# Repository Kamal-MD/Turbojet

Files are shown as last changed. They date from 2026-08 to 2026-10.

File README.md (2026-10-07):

Project description: homemade turbojet made from a salvaged turbocharger, propane fueled, ground test only\
Current Status: Found Turbocharger, broken compressor seal ring but in good condition\
Current Reference: HX35 Turbo\
Key points:
+ Fuel: Propane
+ Compression Ratio: 2.4
+ Air mass flow: 0.212 kg/s
+ Compressor Exit Temp/Combustor Inlet T2: 400K ~ 127C
+ Turbine Inlet Target, T4: 880K ~ 606.7C
+ FAR_stoichiometric: 0.0642
+ φ_overall: 0.19

Note: Not for flight

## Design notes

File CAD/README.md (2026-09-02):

All CAD modeling is done using Autodesk Fusion

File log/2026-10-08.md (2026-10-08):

**What I did:** Determined the φ in each zone, as well as the operating temp of each zone\
**Details:**
+ For the primary zone, we use φ = 1 since that is when the temperature, and therefore the combustion rate is highest. This means it can keep up with the fast flowing air without being extinguished
+ For secondary zone, we use φ = 0.6 (tentative), because it is what is used in most turbojet designs, and because its operating temperature is cool enough for CO2 to remain CO2 without dissociation but hot enough that CO burns into CO2
+ The rest of air goes to dilution, such that the overall  φ = 0.19
+ The operating temps and air splits in each zone are in the table below, which was generated by Claude, and Claude also aided in the calculations:

## Combustor zone design

**φ_overall = 0.189 (calculated), rounded to 0.19 for design.**

| Zone | φ (cumulative) | f | Cumulative air | Air added in zone | T (formula) | Expected real T | Purpose |
|---|---|---|---|---|---|---|---|
| Primary | 1.0 | 0.0642 | 19.0% | 19.0% | ~2551 K | ~2350 K (Cantera to confirm) | Stable flame in recirculation bubble |
| Secondary | 0.6 (provisional) | 0.0385 | 31.7% | 12.7% | ~1775 K | Somewhat lower (Cantera to confirm) | Burn out CO left by primary zone |
| Dilution | 0.19 | 0.0122 | 100% | 68.3% | ~882 K (609 °C) | ~882 K | Cool to T4 target, even out profile |

**Design fuel flow:** 0.0122 × 0.212 kg/s ≈ 2.6 g/s propane

**Formulas:**
- f_zone = φ_zone × FAR_st
- T_zone = T3 + (f · LHV · η_b) / ((1 + f) · c_p)
- X_zone = φ_overall / φ_zone

**Assumptions:** propane, FAR_st = 0.0642, LHV = 46,350 kJ/kg, T3 = 400 K, ṁ_air = 0.212 kg/s, all fuel injected at the flange. c_p = 1.3 / 1.25 / 1.1 kJ/kg·K (primary / secondary / dilution). η_b = 1.0 for hot zones (ideal, comparable to Cantera), 0.95 at exit.

**Notes:**
- Rounding φ_overall up from 0.189 to 0.19 raises T4 from 879.9 K to ~882.4 K (+2.5 K), well inside the 25% margin to the 900 °C turbine limit.
- Primary and secondary temperatures depend only on each zone's own φ, so they're unaffected by the rounding.
- Formula temperatures ignore dissociation, so the hot zones are overestimated.
- Wall-cooling air is not yet allocated; scheduled for Oct 10. It will come out of the 68.3% dilution share.

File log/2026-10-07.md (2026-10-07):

**What I did:** Calculated the stoichiometric Fuel-to-Air ratio for propane (FAR = 0.0642) and the overall equivalence ratio (0.19) that the combustion chamber should run on\
**Details:** To determine the amount of fuel and air to inject, as well as the percentage of air in the chamber zones (in the future), we need the stoich. FAR and overall equivalence ratio:
+ C₃H₈ + 5 (O₂ + 3.76 N₂) → 3 CO₂ + 4 H₂O + 18.8 N₂ (O2 is about 21 percent of air, meaning nitrogen gas is about 79 percent; therefore, there is about 3.76 N2 for 1 O2 (in mols))
+ Using the respective molar masses of the reactants, we see that m(C₃H₈) = 44.1g while m(air)= 686.5g. So stoichiometric FAR = 0.0642
+ This means that 1 kg of air burns around 64 grams of propane
+ The equivalence ratio φ is actual FAR/stoichiometric FAR (where if φ=1 combustion is stoichiometric, if φ<1 it is lean or has leftover O2, if φ>1 it has unburned leftover fuel)

Thus, we have to get FAR_actual:
+ FAR · LHV · η_b = (1 + FAR) · c_p · (T_out − T_in)  (where we have T_in = T2 = 400K or 126Celcius, and T_out = T4 = 880K or 606.7C)
+ LHV = Propane's Lower Heating Value = 46.35 (MJ/Kg); LHV is the amount of heat released when a fuel is completely burned
+ η_b(combustion efficiency) = 0.95 (This is an assumption, since we can know when we run experiments)
+ c_p (average specific heat of the hot gas): ~1.1 kJ/kg·K over this range
+ So, FAR_actual (overall) is around 0.012
+ φ_overall = FAR_actual(overall)/FAR_stoichiometric = 0.012/0.0642 ~ 0.19
  
**Problem:**
+ Propane's lean flammability limit (you could think of it as the equivalence ratio, or percentage of stoichiometric fuel needed to sustain combustion) is φ=0.5, or around 32 grams of propane
+ So we must do 2 contradictory things: Operate chamber at a φ that sustains propane's combustion and have it reach the turbine at φ_overall = 0.19 to avoid damaging it
+ Common practice in dealing with this (as is seen in commercial turbojets) is using zones to admit the air in stages, where the majority of combustion happens in the primary stage and the rest of the stages are used to finish combustion and cool it down

**What to do next:**
+ Figure out the operating temperature for each air zone such that the air reaches the turbine at around 606 Celcius (I don't mind being a little higher than that, but being below means we are losing out on energy. I will explain why in the next log)
+ From the operating temperature, determine the percentage of air that should pass through each zone to maximize efficiency (while remaining safe of course)
+ Granted, I might work on part of this today since I still have some time, but I will log any progress towards this for tomorrow (Oct 8)

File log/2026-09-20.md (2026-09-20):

**What I did:** I Bought a turbocharger and started cleaning it\
**Details:**
+ Went to a junkyard and bought a turbocharger for 30 usd
+ Took it home and started cutting off the exhaust manifold
+ Ran into a material drawback; I didn't have a wheel (for my circular electric saw) that was big enough to cut all the way through the exhaust manifold\
  
**Note:** Post pictures showing you cutting the manifold\
**What to do next:**
+ Since I can't get the wheel for a while, I'll clean the turbo, disassemble it, clean it from the inside
+ After that, I will look up the model and take measurement of the intake and outlet for both the turbine and compressor and measure turbine housing thickness to determine temp ceiling
+ Finally, I will check the model in hopes of finding a compressor map for the turbo

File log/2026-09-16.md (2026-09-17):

**What I did:** Determined Turbine inlet temp ceiling\
**Details:**
+ From the following source (https://www.mambatek.com/en/products/mamba-d5-turbo-turbine-wheel-for-holset-hx35hx40-dodge-cummins-647655), material of HX35 is 713C Inconel
+ 713C Inconel has a  continuous-duty max operating temperature of around 980C, which I will be decreasing to 900C for safety reasons

**What to do next:**
  + Determine the turbine inlet temp (T3) that we want to operate at, account for safety margin
  + After determining T3, we will use it to determine fuel to air ratio
  + Check if the power generated is greater than compressor power demand, so that the engine self sustains and produces thrust

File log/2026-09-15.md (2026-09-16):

**What I did:** Short Session, I just set the goals and limitations to consider when building the combustion chamber\
**Details:**\
I set the following to take work on:\
**P1**
+ **Turbine inlet temperature ceiling** to make sure the turbine and turbine housing can handle the temperature of the air coming from the combustion chamber
+ **Chamber Liner tolerances and survival** which entail making sure that the chamber housing can tolerate peak temperatures without warping or burning through
+  **Accounting and minimizing for loss of pressure in chamber**

**P2**
+ **Combustion efficiency** (Helps minimize soot buildup among other things)
+ **Flame stability across operating range** to make sure that the engine can run during all stages (startup, throttle changes, etc.) and not just on one design point (which is the goal 28 lb/min (0.2117 kg/s)
+ **Make sure that temperature is uniform at the exit** (without hot streaks, since those will be the actual temp ceiling, not the average temp)

**P3**
+ **Ignition/startup reliability** (Can I source an igniter that can light it during startup?)
+ **Material sourcing feasibility**

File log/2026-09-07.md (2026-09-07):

**What I did:** Determined what the chamber inlet diameter should be\
**Details:**
+ Determined air density at compressor discharged since mass flow alone doesn't tell you velocity through a duct, you need density too. Used the ideal gas law: ρ = P / (R × T)  
Where:\
P = compressor discharge pressure = PR × P1 = 2.4 × 101,325 Pa ≈ 243,180 Pa\
R = specific gas constant for air = 287 J/(kg·K)\
T = compressor discharge temp = 400K (calculated in the Sept 1 session)\
And thus we got: ρ2 = 243,180 / (287 × 400) ≈ 2.12 kg/m³
+ Unlike the chamber inlet (a free design choice), the compressor's own outlet diameter is fixed hardware — 52mm ID, per the HX35 V-band spec. So velocity here isn't chosen, it falls straight out of known geometry via continuity:\
ṁ = ρ × A × V  →  V = ṁ / (ρ × A)\
Where:\
m = 0.2117 kg/s\
A (52 mm compressor outlet inner diameter) = π × (0.026)² ≈ 0.002124 m²\
Which gives us: V2 = 0.2117 / (2.12 × 0.002124) ≈ 47 m/s
+ Then to determine velocity across the connector's changning diameter I used:\
ṁ = ρA₁V₁ = ρA₂V₂\
Density is approx. constant over this short, low-Mach run, so it cancels:\
A₁V₁ = A₂V₂  →  V₂ = V₁ × (A₁/A₂)\
Since A = π(d/2)², the π/4 factor is on both sides and cancels too — area ratio becomes a diameter-squared ratio:\
A₁/A₂ = (d₁/d₂)²  →  V₂ = V₁ × (d₁/d₂)²\
+ First I applied this math along the compressor outlet, which starts at V1=47m/s and 52mm diameter as d1 (directly at the compressor outlet with the 52mm inner diameter)
and then 75.5 mm as d2, which is the diameter of the silicone hose at the compressor end. Thus, we get the air velocity at the compressor end of the hose to be ~22.3m/s
+ Then to determine the velocity at the chamber inlet, we use V1 = 22.3m/s, d1 = 75.5 mm (which is the hose inner diameter on the compressor end), and d2 =50 mm, which is the inner diameter placeholder we put in September 1's session.\
As such we get the chamber inlet velocity at ~51 m/s
+ Since the the inlet velocity of 51m/s agrees with most DIY turbojet literature (I don't have exact sources for radially arranged turbocharger turbojets, only for axially arranged turbojets), we are keeping the chamber inlet diameter as 50 mm and will widen the silicone hose to 50.5mm inner diameter to fit over it

**What to do next:**
+ Determine combustion chamber geometry
+ Will likely design the inlet stub as part of it, but this might change
+ Thoroughly plan how to design the combustion chamber

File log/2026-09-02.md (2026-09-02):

**What I did:** Changed compressor to chamber connector material from Aluminum to Silicone hose and modeled the silicone hose with a placeholder value\
**Details:**
+ Created a model for the HX35 compressor outlet in CAD for future reference: HX35 comp ref
+ Due to sourcing difficulties in Lebanon and the technical difficulty of making an Aluminum connector tube with a V-band flange, I decided to switch to using a silicone hose as a connector
+ This decision is due to the fact that silicone hoses can resist extreme temperatures of up to 250 degrees Celsius, which is a great margin over our projected compressor discharge temp of around 127 degrees (150 degrees in extreme cases and random spikes of temp)
+ The logic behind it is that I will buy a hose with an inner diameter slightly greater than that of the compressor outlet's V-band lip (74mm OD) and use a hose clamp behind the lip to create an airtight seal
+ Ideally, I would buy a hose of an inner diameter at the compressor end that differs from the diameter on the chamber end (Note: the hoses diameter at the compressor end is fixed at 75.5 mm, while the decision of having a smaller diameter at the chamber end can be subject to future change) 
+ This is the CAD file of the current version I made today:
placeholder comp to chamber connection

Dimensions:
+ **Hose compressor end inner diameter:** 75.5 mm
+ **Hose chamber end inner diameter:** 50 mm
+ **Hose wall thickness:** 4.5 mm
+ **Hose length:** 200 mm

**What to do next:**
+ Calculate the chamber inlet diameter
+ Model chamber inlet in CAD

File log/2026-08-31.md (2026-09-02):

**What was done:** Learned how to use CAD and settled on HX35 specs to use for reference\

**Details:**
+ Finished Days 1 to 9 in Product Design Online's 30 day Autodesk Fusion Course
+ Holset's official Service Repair Manual and Service Data Sheet don't publish flange bore/OD dimensions, so I used an HX35 listing (https://www.turbozentrum.de/Holset-HX35-Turbo-12cm_1) as reference
+ Did not do much Turbojet related CAD modeling today, but resolved whether the mounting type was V-band or bolted and on which side. 
+ Locked in [reference specs](/References/HX-35_Turbo.md), which will set up for Sept 1 and 2's session
  
**What to do Next:**
+ Model Compressor Outlet to Combustion Inlet connection
+ Specify Compression Ratio and Air conditions in the Combustion Inlet here on Github

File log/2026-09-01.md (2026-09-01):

**What was done:** Calculated Compressor Outlet Temperature, Material to use for Compressor to Chamber connection, Determined Compression Ratio and Energy the compressor requires\
**Details:**
+ The material to use for the compressor outlet to chamber inlet connection will be Aluminum, as its melting point is 660 degrees Celsius and the compressor discharge temperature is well below that (unlikely to exceed 150 degrees) Note: This decision can be subject to future change
+ To determine what material to use for the compressor outlet to chamber inlet connection, I had to determine Compressor Outlet Temperature. This was achieved by using the following equation:

  $$
  T_2 = T_1 \left[ 1 + \frac{PR^{\frac{\gamma - 1}{\gamma}} - 1}{\eta_c} \right]
  $$

  Where:\
  T1 = inlet air temperature (in Kelvin(K), ~ 288K on a normal day)\
  T2 = compressor discharge temp (in Kelvin)\
  PR = Pressure Ratio (or Compression Ratio)\
  gamma (y) = specific heat ratio for air (approximately 1.4)\
  n_c = compressor isentropic efficiency (meaning how efficient it is and how much goes towards internal losses such as turbulence and friction), typically around 0.65 - 0.75 for a turbocharger like this

  But keep in mind that the compression ratio (PR) has not been decided at this point (we need to determine a ratio where this specific turbo can run efficiently)
  
+ So, I found a compressor map for HX35 (which was unofficial but detailed) in the following link: (https://www.dsmtuners.com/threads/how-to-read-the-hx35-hx40-compressor-map-s.362599/)\
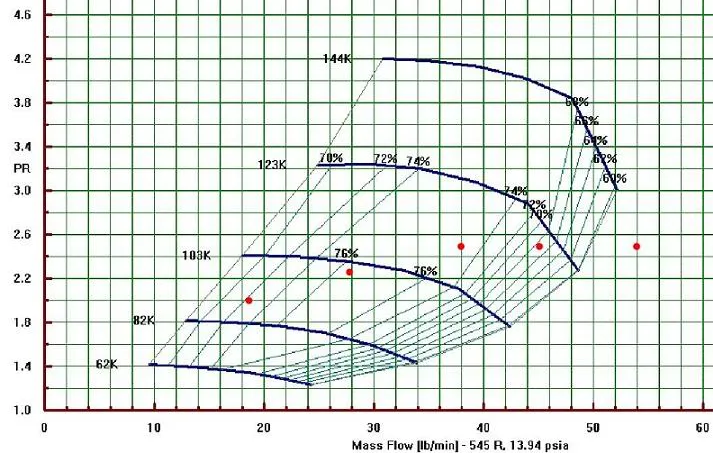
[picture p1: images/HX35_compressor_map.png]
HX35 Compressor Map
  This is it:
+ In reference to the map, we can see that an optimal efficiency of 76% is achieved at between a PR of 2.2 and 2.4. We will pick PR of 2.4
+ We are using n_c = 0.75 which is inferred off the map, since PR of 2.4 sits between 74% and 76.5% efficiency (so we will use 75% or 0.75 as a place in between)
  By inputting PR = 2.4 into the above equation, we get T2 ~ 400 Kelvin (specifically is 397K) which is around 127 degrees Celsius
+ Finally, we determined the work the compressor requires through the following equation:

$$
W_{\text{compressor}} = \dot{m}_{\text{air}} \cdot c_p \cdot (T_2 - T_1)
$$

Where: 

m(air) = mass flow rate of air (which I picked to be 28 lb/min or 0.2117 kg/s by looking at the map intersection of PR=2.4 at ~76% efficiency)\
c_p = specific heat for air ( around 1005 J/Kg*K)

And thus we get Wcompressor = 0.2117 kg/s * 1005 J/Kg*K * 112 K = 23.8 KW (KiloWatts)

**What to do next:**\
Tomorrow  on Sept 2:
+ I will design the compressor to chamber connection in CAD using Autodesk Fusion
+ If I have time, I will see how to figure out the power the turbine consumes and if the engine can self sustain (as I can't find a turbine map for HX35 turbo)

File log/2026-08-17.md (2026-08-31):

**What I did**: Decided on welding, materials for combustion chamber, and position of propane inlet\
**Decisions**:
+ I will weld the flanges onto the combustion chamber. First, I will weld the inner liner to the inside to the flange and the flange to the combustion chamber. Additionally, I will weld a flange onto the end of the chamber to fashion a flange joint on the turbine intake
+ The type of welding will be stick welding since I have a 50$ stick welding machine that fits within my budget
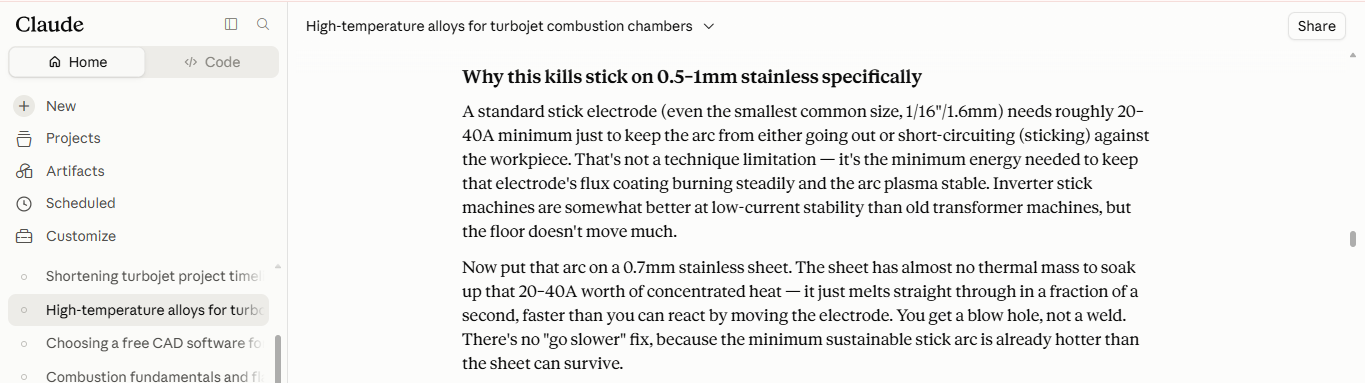
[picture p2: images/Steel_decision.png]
Steel decision
+ The base current needed to sustain stick welding, in most cases, is 20 to 40 amps, so I will use 2.5 mm steel since 0.5 - 1 mm steel with melt before I can get any welding done, due to the high current
+ The steel I will use is 304 stainless steel, as it is cheaper than other high performance alternatives (such as 321 and 316L), handles up to 870 Celsius, and is easier to source in Lebanon 
+ The combustion chamber air inlet will be in the side of the housing of the combustion chamber, which will help us achieve the toroidal circulation of hot gas (also know as a recirculation bubble) that makes sustained combustion possible
+ Propane inlet will be located in the center of the flange, which is mounted at the beginning of the combustion chamber, and that is because, at that position, the propane will be directly injected into the recirculation bubble and that directly helps us self-sustained combustion\
**What to do Next**: Find somewhere to buy the turbocharger from, and determine what instruments are needed for measuring the turbojet properties during test runs

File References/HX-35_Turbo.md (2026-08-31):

**Holset HX-35 Turbocharger Specs**
+ **turbine inlet type:** "T3 divided, bolted, 4 bolts"
+ **turbine downpipe Outer Diameter:** 79 mm V-band OD, turbine downpipe side
+ **turbine downpipe Inner Diameter:** 65 mm V-band clamp bore, turbine downpipe side
+ **turbine wheel inlet:** 70 mm turbine wheel inducer (informational, not a mating dim)
+ **turbine wheel outlet:** 60 mm turbine wheel exducer (informational)
+ **turbine housing Area:** 12 cm², informational only, doesn't drive geometry
+ **compressor inlet bore:** 102 mm compressor housing intake
+ **compressor outlet Outer Diameter:** 74 mm V-band OD, compressor outlet
+ **compressor outlet Inner Diameter:** 52 mm V-band clamp bore (Inner Diameter), compressor outlet
+ **compressor wheel inlet:** 52 mm compressor wheel inducer (informational)
+ **compressor wheel outlet:** 77 mm compressor wheel exducer (informational)

**Note:**
+ Turbine Inducer is the where the gas/fluid enters the turbine wheel
+ Turbine Exducer is where it exits the turbine wheel (where turbine inducer diameter is generally larger than exducer diameter)

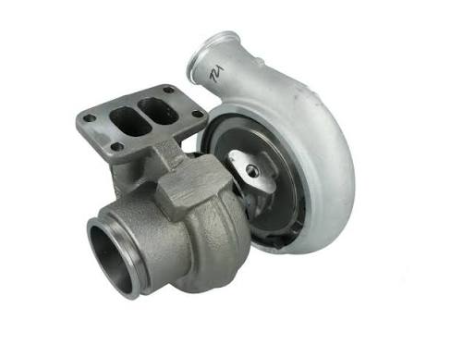
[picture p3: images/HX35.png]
HX35 Turbine inlet
  \
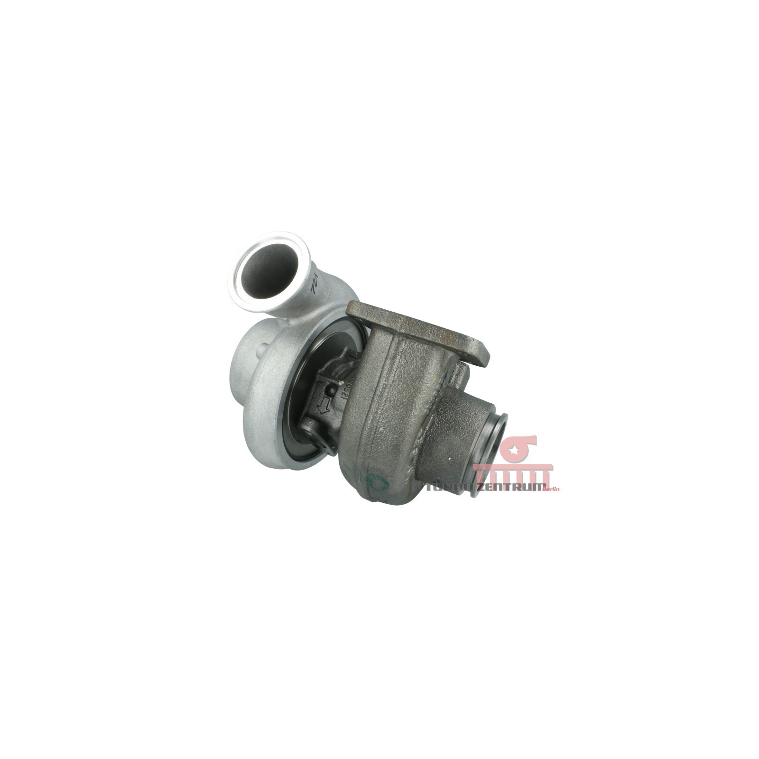
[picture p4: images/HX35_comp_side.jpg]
HX35 compressor outlet


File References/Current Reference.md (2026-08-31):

**Note:** This file dictates what turbocharger is being used as reference in what point in time\
**Current Reference**: HX-35 Turbocharger\
**Previous References:** N/A

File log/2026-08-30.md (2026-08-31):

**What I did:** Decided on modeling the combustion chamber in Autodesk Fusion using HX-35 as point of reference\
**Decisions:**
Due to difficulty in sourcing a turbocharger (that fits within budget) in Lebanon, I will model the combustion chamber in CAD using HX-35 turbocharger as reference. If I get an actual turbocharger, I will adjust the dimensions accordingly.

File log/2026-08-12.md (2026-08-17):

**What I did**: Determined requirements\
**Decisions**:
+ Will use plumbing fixtures and gaskets to attach compressor outlet to combustion chamber intake, as it is easier and more practical
+ Will weld a flange to the end of the combustion chamber and fashion a flange joint, with a gasket in the middle, to attach the chamber to the turbine intake
+ Will use spark plug for ignition, and thus will have to fashion a remote controlled circuit to trigger the spark plug
+ Will use an adjustable valve on the propane tank to control throttle
**What's Next**: Figure out material to use for combustion chamber and the welding decision

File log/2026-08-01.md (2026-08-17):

**What I did**: Decided to what fuel to use and which parts will be self-fabricated/welded, and which parts will be salvaged\
**Decisions**:\
Turbocharger will be salvaged or bought from a breaker that salvaged it; HX-35 Turbocharger is preferred as it is able to self-sustain but small enough to be easier to handle and more forgiving in preliminary tests in case something goes wrong\
**What's next**: Determine requirements for the build

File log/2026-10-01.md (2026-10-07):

**What I did:** Determined Turbine inlet temp (which I will call T4) to be 606.7 Celcius (logged Oct 7)\
**Note:** I am calling Turbine inlet T4 and not T3 since this is standard practice (technically combustor inlet should be T3 but I already set it to T2)\
**Details:**
+ Since 713C Inconel has a temperature creep limit of around 920 Celcius, we will take the limit as 900 degrees celcius to be conservative
+ This means the T4 + margin for hot streaks (which are spikes above the average operating temp)  <= 900 Celcius
+ I took the margin to be 25 percent. 900 Celcius = 1173.15 Kelvin (which I am using since it is a more physically meaningful way to measure temp)
+ so T4 = 1173.15K *(1-0.25) = 879.86K or around 606.7 Celcius

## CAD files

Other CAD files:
CAD/compressor_to_chamber_connection_v0.f3d
CAD/hx35_comp_outlet_ref.f3d

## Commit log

2026-08-17 Add files via upload
    Troubleshooting with Claude on why 1 mm steel is incompatible with stick welding, and on which turbocharger is best for my needs
2026-08-31 Create Current Reference.md
2026-10-29 Add parametric CadQuery combustor model
    combustor_model.py builds the 15 combustor parts (flanges, head pipe,
    stub, step plate, housing, end plate, head ring, gaskets, liner with all
    hole rows, spacers, M4 bolts, slip sleeve, fluid volume) in one global
    frame from a single PARAMETERS block, runs PASS/WARN design checks and
    exports STEP files. Replaces the folder placeholder.
    Claude-Session: https://claude.ai/code/session_01ASaNhmihzLuGsHRtx68eJM
2026-10-29 Add generated STEP files, checks, parameters and README
    Output of combustor_model.py: one STEP per part, assembly.STEP,
    fluid_volume.STEP, half_section.svg, parameters.csv and checks.txt
    (32 PASS, 0 WARN). README explains how to run and what each output is.
    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
2026-10-29 Reclock hole rows, shrink inlet stub, add slip and clocking checks
    - phase_sec, phase_dil1, phase_dil2 now derived from n_sec / n_dil_row
    (half secondary pitch, 1/8 dilution pitch, row 2 half a pitch later)
    - flange_t 14 -> 15 (placeholder), stub_OD 55 -> 50, stub_ID derived
    as stub_OD - 2*wall (45); stub_x 61, head_L 96
    - New checks: row-to-row angular separation, slip-sleeve hot radial and
    axial clearance, sleeve leak area, inlet stub velocity, step plate and
    stub spacing
    - Re-exported all STEP files, parameters.csv, checks.txt and section
    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
2026-10-29 Rework clocking and slip checks, add dump loss and STEP read-back
    - phase_dil1 is now an input (2.5714 deg); phase_dil2 follows (28.2857)
    - Clocking: cooling-row pairs reported as INFO; WARN if any other pair
    is closer than 2.5 deg
    - Slip sleeve: hot radial clearance and leak area for sleeve at 400 K
    and 700 K, crediting sleeve growth; WARN only below 0.1 mm at 400 K;
    anti-seize shop note
    - INFO: inlet dump loss and total combustor pressure loss (% of P3)
    - verify_step.py reads 11_main_liner.STEP and assembly.STEP back after
    every export and writes output/verify.txt
    - Re-exported all outputs
    Claude-Session: https://claude.ai/co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
2026-10-29 Update READMEs for the 2026-10-29 combustor redesign
    Top-level README: new air split (5% film cooling, 63.5% dilution), film
    joint description, combustion chamber geometry section (construction,
    liner holes, checks, open items) and status line.
    Combustor_Design README: stub is now 50/45, document hole clocking.
    Claude-Session: https://claude.ai/code/session_01ASaNhoSVEBuiYiXAitVY68
